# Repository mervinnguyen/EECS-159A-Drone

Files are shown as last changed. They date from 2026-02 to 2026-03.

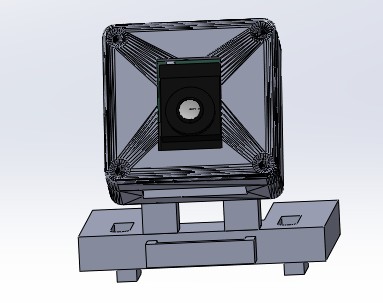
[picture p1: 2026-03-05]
3D Printed Parts/Full Camera Mount Assembly 2.jpg

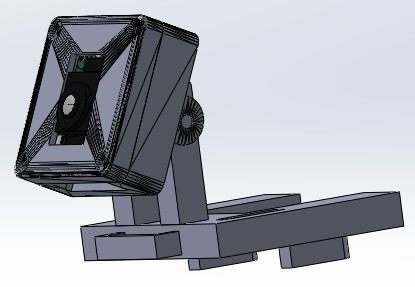
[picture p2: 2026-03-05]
3D Printed Parts/Full Camera Mount Assembly.jpg

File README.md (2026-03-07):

# PhotonFlight: Fiber-Optic Autonomous UAV

PhotonFlight is a **fiber-optic-tethered autonomous quadcopter** designed for operation in **RF-denied or GPS-degraded environments**.  
The platform replaces traditional RF telemetry with a **secure bidirectional SFP fiber link**, enabling **low-latency video streaming, real-time telemetry, and reliable command/control communication** between the UAV and ground control station.

The system integrates **ArduPilot flight control, embedded Linux module, onboard AI vision processing, and fiber-optic networking**, demonstrating a complete embedded system spanning hardware, firmware, networking, and autonomy.

---

# Abstract

PhotonFlight is a **fiber-optic tethered UAV platform** developed for search-and-rescue and infrastructure inspection applications where traditional RF communication may be unreliable or unavailable.

The system leverages **single-mode fiber optic communication via SFP transceivers** to provide:

- RF-interference immunity  
- secure high-bandwidth communication  
- low-latency telemetry and video streaming  

An onboard AI camera enables **real-time object detection and autonomous tracking**, while a companion computer processes video and coordinates communication with the flight controller.

The result is a **robust embedded UAV platform capable of operating in communication-contested environments**.

---

# System Architecture

PhotonFlight is composed of several integrated system layers that enable flight control, telemetry transmission, and onboard intelligence.

Each layer performs a specific role in the overall system.

| Layer | Responsibility |
|---|---|
| Ground Control Station | Mission planning, telemetry monitoring, system control |
| Fiber Communication Layer | Secure telemetry and high-bandwidth video transmission |
| Companion Computer | AI inference, video processing, communication bridging |
| Flight Controller | Real-time stabilization, sensor fusion, flight control |
| Motor Control | Direct actuation of propulsion system |

e
---

# Hardware Architecture

PhotonFlight is built using a combination of **commercial off-the-shelf components and custom fabricated hardware**.

## Airframe

The UAV uses an **8-inch quadcopter carbon fiber frame** providing structural mounting for propulsion, avionics, and communication hardware.

Key design considerations include:

- vibration isolation
- weight optimization
- secure component mounting

---

## Propulsion System

The propulsion system consists of:

- **Brushless DC motors (BLDC)**
- **high-efficiency propellers**
- **electronic speed controllers (ESCs)**

ESCs receive control signals from the flight controller to regulate thrust and maintain stability.

---

## Power System

The drone is powered by a **high-discharge LiPo battery** distributed through a **Power Distribution Board (PDB)**.

The power subsystem manages:

- high-current delivery
- electrical isolation
- voltage regulation for onboard electronics

Battery safety procedures and charge management protocols are implemented for safe operation.

---

# Flight Control System

The UAV uses an **ArduPilot-based flight controller** responsible for deterministic flight control.

Responsibilities include:

- attitude stabilization
- sensor fusion
- waypoint navigation
- flight mode control
- failsafe management

The controller integrates multiple onboard sensors:

- IMU (accelerometer + gyroscope)
- magnetometer
- barometer
- GPS receiver

Flight control commands are communicated via **MAVLink protocol**.

---

# Companion Computer

A **Raspberry Pi 4** acts as the onboard companion computer, providing high-level processing capabilities.

The companion computer is responsible for:

- AI inference and object detection
- video encoding and streaming
- communication routing between sensors and ground station
- system coordination

The Raspberry Pi communicates with the flight controller through **MAVLink interfaces**.

---

# Fiber-Optic Communication Pipeline

PhotonFlight replaces traditional RF telemetry with a **fiber-optic communication architecture**.

The system uses:

- **SFP transceivers**
- **single-mode fiber optic cable**
- **media converters**

This communication architecture provides several advantages:

- immunity to RF interference
- secure communication channel
- high-bandwidth data transmission
- reduced telemetry latency

Data transmitted through the fiber link includes:

- MAVLink telemetry
- AI camera video feed
- mission control commands

---

# Vision System

PhotonFlight incorporates two vision modules enabling perception capabilities.

## Infrared Camera

The infrared camera enables **thermal imaging and low-light operation**, allowing the UAV to function in environments such as:

- disaster response zones
- low visibility environments
- nighttime search-and-rescue missions

---

## AI Camera

The onboard AI camera performs **real-time object detection and tracking** using pretrained neural network models.

Capabilities include:

- autonomous target tracking
- real-time object detection
- visual feedback to ground operators

Inference can be executed onboard or streamed for external processing.

---

# Ground Control Station

A ground control station running **Mission Planner or QGroundControl** enables operators to:

- monitor real-time telemetry
- upload mission waypoints
- visualize system status
- issue control commands

Communication between the UAV and the ground station occurs over the fiber link.

---

# Safety Systems

Several redundant safety mechanisms are implemented to ensure safe operation.

These include:

- geofencing
- return-to-launch (RTL)
- emergency failsafe procedures
- pre-flight validation checklists

These systems mitigate risk during autonomous flight operations.

---

# Key Technologies

PhotonFlight integrates multiple hardware and software technologies:

**Flight Control**
- ArduPilot
- MAVLink

**Embedded Systems**
- Raspberry Pi 4
- embedded Linux

**Networking**
- fiber-optic SFP communication
- telemetry streaming

**Perception**
- onboard AI camera
- computer vision inference

---

# Documentation & Project Resources

Project documentation and development artifacts are maintained collaboratively.

Resources include:

- system architecture documentation
- hardware integration notes
- flight test logs
- telemetry data analysis
- design review presentations
- safety procedures and compliance documentation

---

# Project Focus

PhotonFlight demonstrates the integration of:

- embedded flight control systems  
- secure communication infrastructure  
- onboard AI perception  

into a UAV platform capable of operating in **RF-contested or GPS-degraded environments**.

This project highlights the application of **embedded systems engineering, networking architecture, and autonomous robotics** in real-world mission scenarios.

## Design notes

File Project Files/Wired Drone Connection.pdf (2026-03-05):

C

o

n

n

e

c

# tin

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
# Mis

# sio

n

# Pla

n

n

e

r

# Drone Info

Connection Info:
static ip_address=192.168.1.100/24 (you can find with photonflight.local; subnet mask is 255.255.255.0)
Port: 5678

Use RX4&TX4 on the flight controller side.

Pi needs to be connected to Vx and Gnd for power; reason being that Vx can supply more current than the other pins.
Currently, the Pi is connected to serial2 on the flight controller

Credentials
Username: photonflight

### Password: *rZ866Qr8!IRnr

Power:
Vx and Gnd from Servo side of the flight controller board

Camera Code Required:

rpicam-vid -t 0 \ --width 1920 --height 1080 --framerate 30 \ --codec h264 --profile high --level 4.1 --inline \ --post-process-file /usr/share/rpi-camera-assets/imx500_mobilenet_ssd.json \ -o - \ | gst-launch-1.0 fdsrc \ ! h264parse \ ! rtph264pay config-interval=1 pt=96 \ ! udpsink host=192.168.1.155 port=1110

Prof. Burke’s install script: https://github.com/mavlink-router/mavlink-router

# Mission Planner Info

Network Settings:
Laptop IP: 192.168.1.155
Subnet Mask: 255.255.255.0
Connect via TCP to port 5678

Firewall Settings:
Go to “Network & Internet” -> “Advanced Network Settings” -> “Advanced Sharing Settings” Turn on Network Discovery inside of Private Networks

Camera Code Required:
udpsrc port=1110 caps="application/x-rtp, media=video,

### encoding-name=H264, payload=96" ! rtph264depay ! h264parse ! avdec_h264 ! queue max-size-buffers=1 max-size-bytes=0 max-size-time=0 leaky=2 ! videoconvert ! video/x-raw,format=BGRA ! appsink name=outsink sync=false

# Instructions

1. Connect drone to laptop via fiber optics and ethernet
a. Raspberry pi -> ethernet -> SFP on drone
b. SFP on drone -> fiber -> SFP on laptop
c. SFP on laptop -> ethernet -> laptop

### 2. For camera make sure it is connected before the Pi gets power. Otherwise a

reboot is required.
3. First turn on drone by connecting main battery
4. Wait for flight controller to beep and for raspberry pi to turn on and run scripts
a. To check to see if the Pi is running by pinging 192.168.1.100 in the terminal
5. On Mission Planner select TCP and connect to 192.168.1.100 at port 5678
6. Mission Planner should be pulling data over the wired connection and relaying that information back to the laptop

### 7. Joystick Config:

a. Then connect the radio controller to Mission Planner via USB type C cable
b. Make sure radio controller is running in wired joystick mode
c. Go to setup -> joystick and then configure the controller

### 8. If using Fiber:

a. To start video:
i. Right Click on HUD
ii. | Hover over “Video”
iii. | Click “Set Gstreamer Source”
iv. | Paste in string from Mission Planner Info
v. Hit Enter, should get a feed onto the HUD

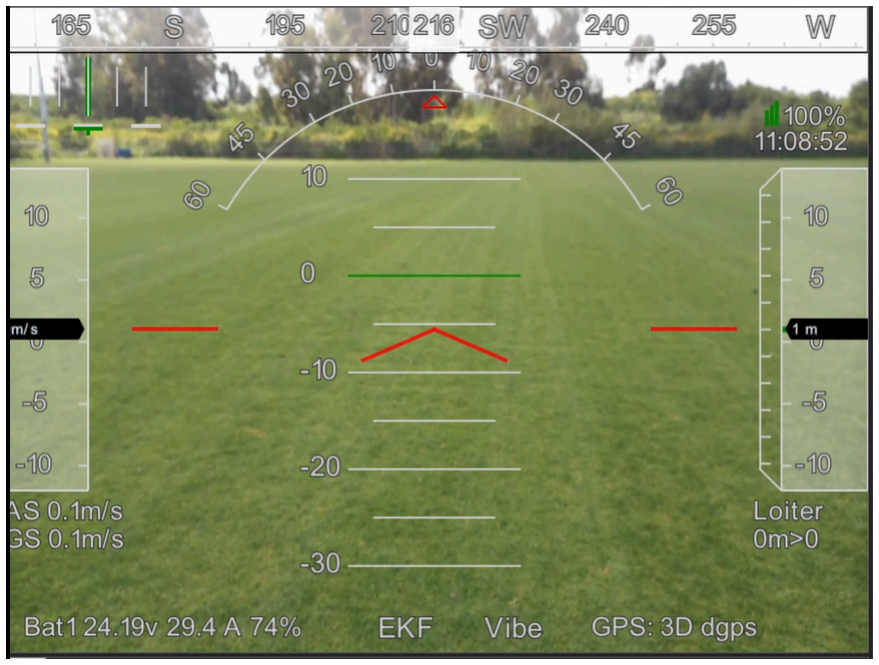
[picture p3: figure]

# Findings (1-28-26)

- We hooked up RX & TX on the flight controller side to Serial 4. Checked the parameter file and saw that baud rate & communication protocol weren’t set correctly
- Changed the baud rate to 57600 (57 in settings), and changed protocol to MavLink2 (2 in settings)
- On Pi Tx4 is plugged into GPIO 15 (Rx)
- Rx4 is plugged into GPIO 14 (Tx)
- After rebooting flight controller we are able to connect without issues

# Joystick Config

1. Setup -> Optional Hardware -> Joystick
2. https://ardupilot.org/copter/docs/common-joystick.html
3. The channels that Burke setup are going to match the RC #s listed in the setup menu
a. EX: RC1 deals with Aileron which means rolling left and right (tilt). So we hit auto detect and move the stick that deals with rolling left and right. This happens to be the one that maps to the X axis of the controller

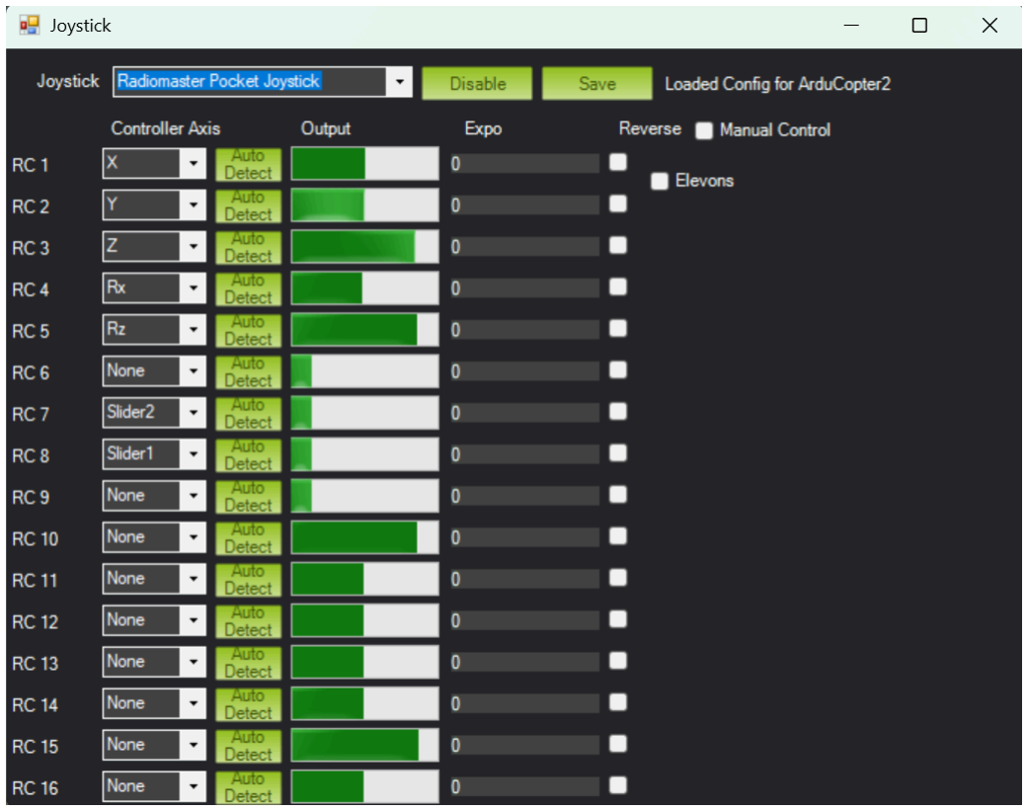
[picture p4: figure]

As of 1-28-26

# Turning On The Camera

This is assuming the connection has been setup and that you have SSH’d into the Pi.
1. First navigate to the folder with the code:
cd Projects/EECS-159A-Drone/Vision\ Tracking\ pipeline/
2. Activate the venv (Virtual Environment):
source .venv/bin/activate
3. You should now see a (.venv) in green text on the left of your terminal
4. Execute the program:
python3 Object_Tracking.py
5. Now the program will first:
a. Connect to the drone (using the same port as mission planner 5678)
b. And then upload firmware to the camera (this is when the loading bar appears)
c. A menu will print out as the loading bar appears and then will get pushed up by more text
d. TLDR it should look like this:

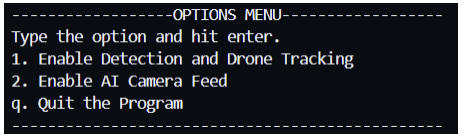
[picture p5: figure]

6. Select an option (use #2 if you do not want the drone to react to objects)
a. Press 1 or 2 and hit enter
b. Drone must be armed before it can react
c. 1 and 2 will start object detection on Mission Planner (assuming you’ve already set that up by pasting the long string into Gstreamer)
7. When you want to quit press: Ctrl + C
8. That will exit you back out to the menu; the camera glitching is normal because the program will restart the camera
9. To fully quit the menu press Ctrl + C again or press q and hit Enter

### 10. If you want to rerun the program (assuming you haven’t done anything else) just

go back to step #4

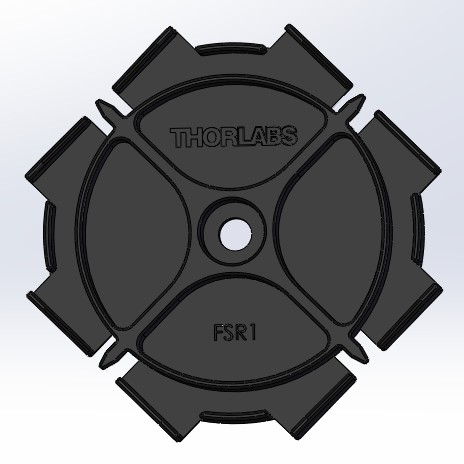
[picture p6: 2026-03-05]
3D Printed Parts/Fiber optic Cable Holder.jpg

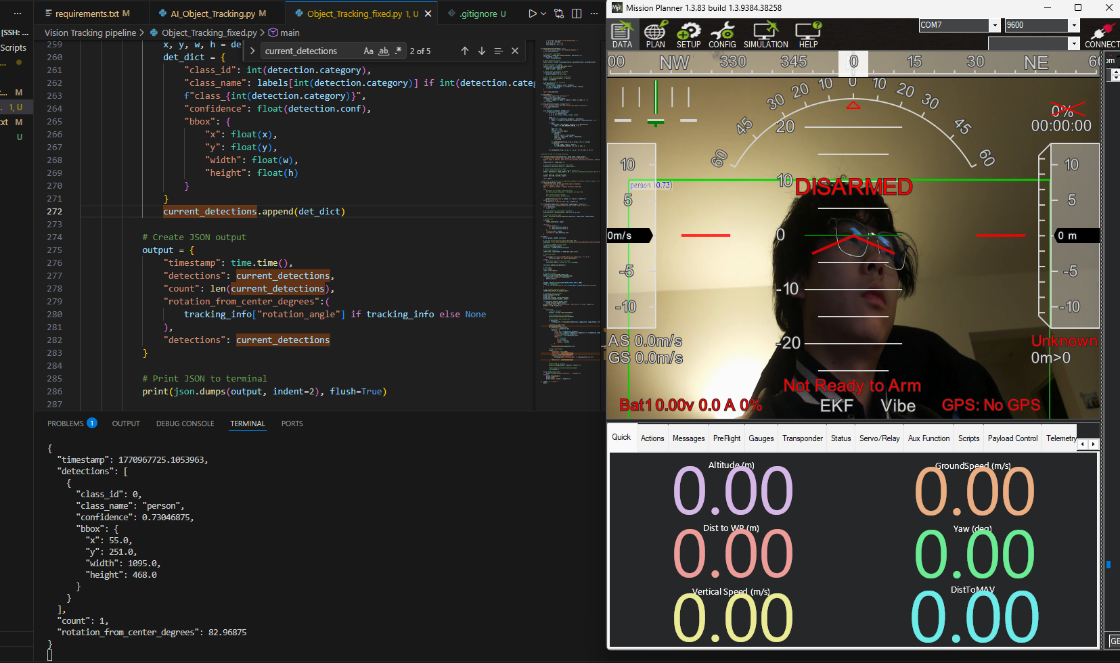
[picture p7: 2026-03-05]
Vision Tracking pipeline/assets/image.png

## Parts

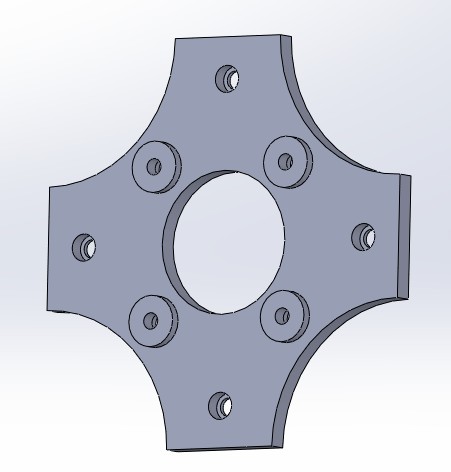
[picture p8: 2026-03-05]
3D Printed Parts/ESC Mount.jpg

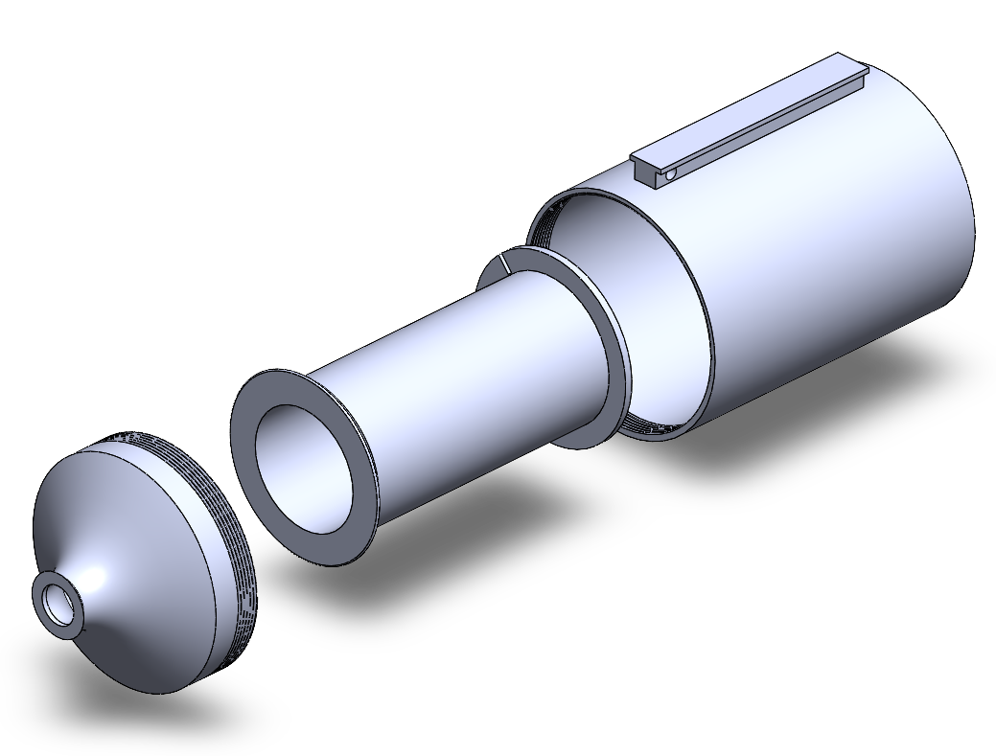
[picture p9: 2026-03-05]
3D Printed Parts/Fiber spool.png

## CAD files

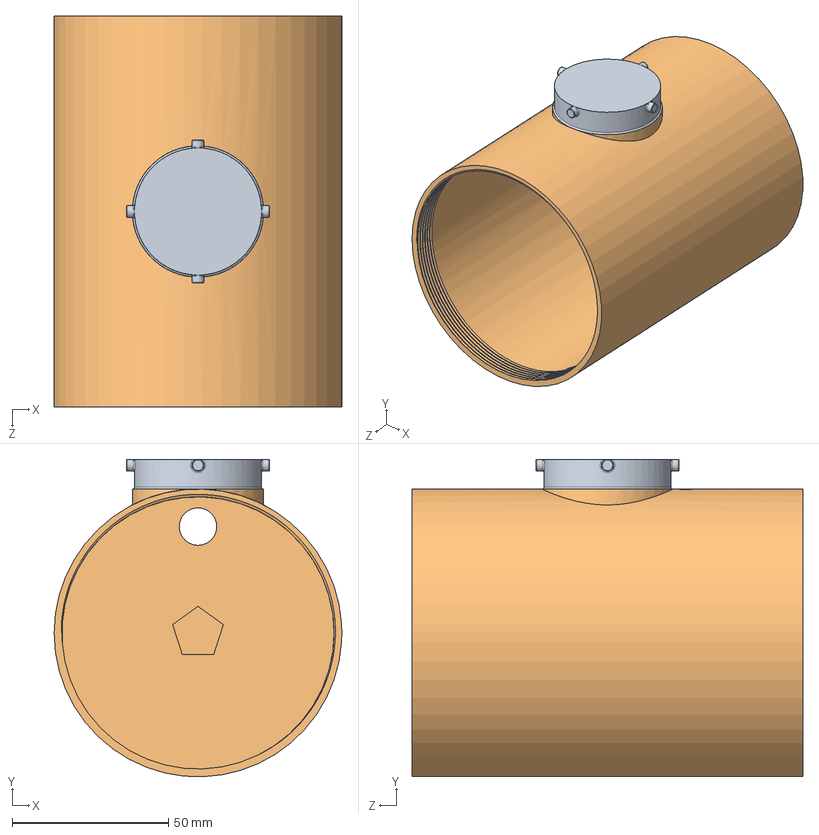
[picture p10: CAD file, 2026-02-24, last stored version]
3D Design Files/Fiber spool on drone.SLDASM
92.0 x 101.5 x 125.0 mm
New spool external housing
Twist Lock Enclosure Male

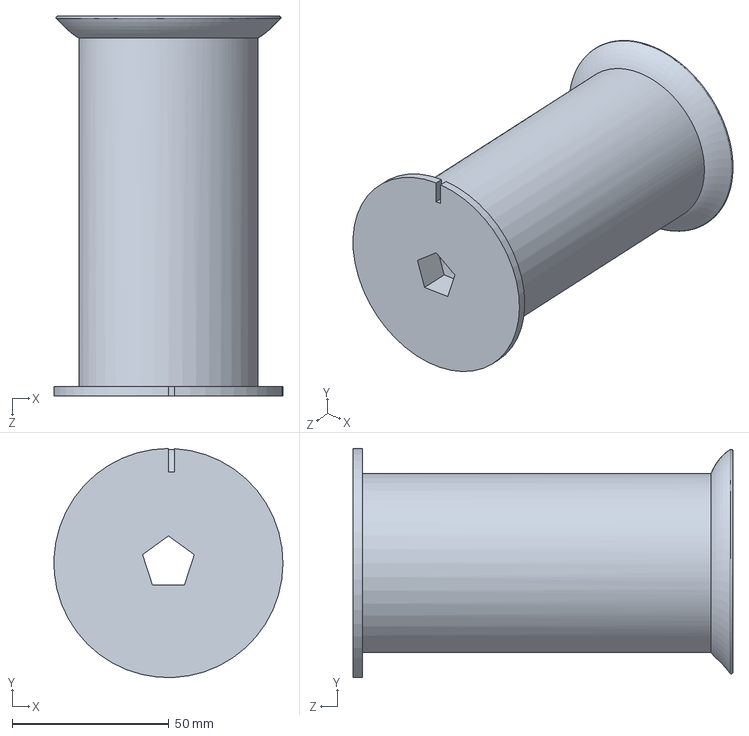
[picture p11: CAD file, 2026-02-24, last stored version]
3D Design Files/New spool internal barrel.SLDPRT
73.0 x 73.0 x 121.0 mm

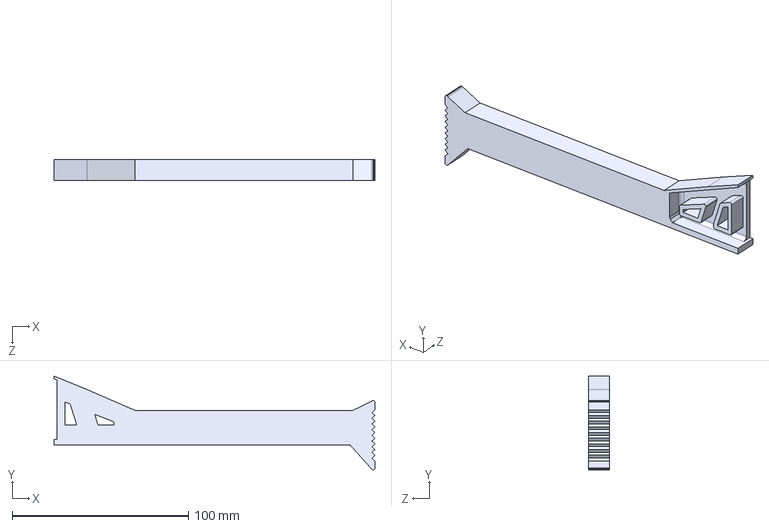
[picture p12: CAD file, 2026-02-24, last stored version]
revised_leg_2.22.26_long_af.STEP
182.3 x 53.3 x 12.0 mm

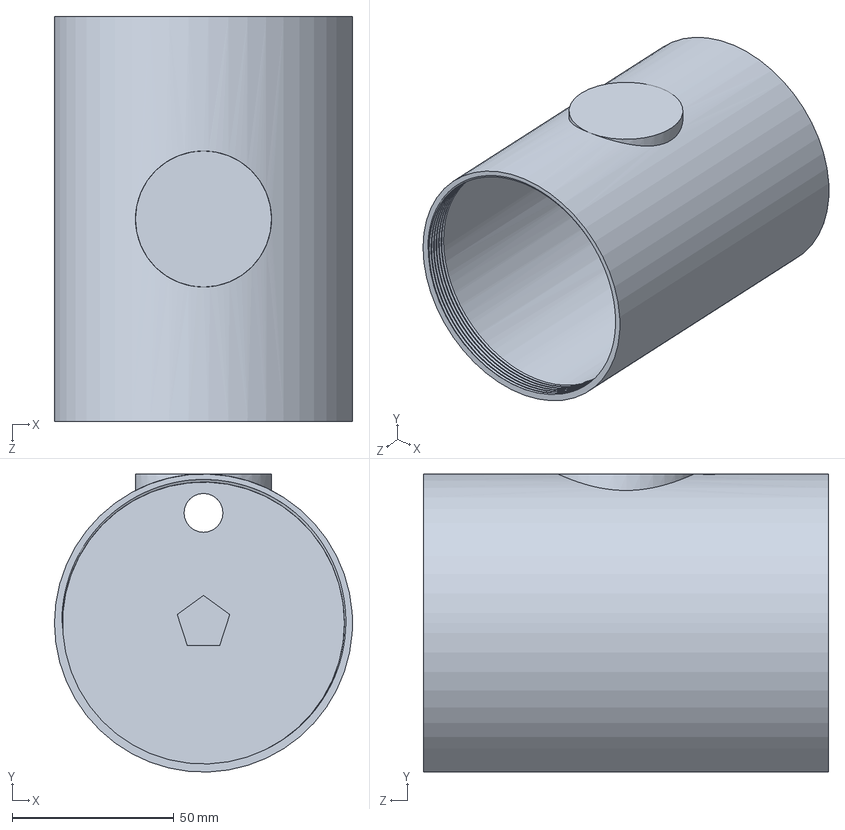
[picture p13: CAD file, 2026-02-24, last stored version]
3D Design Files/New spool external housing.SLDPRT
92.0 x 92.0 x 125.0 mm

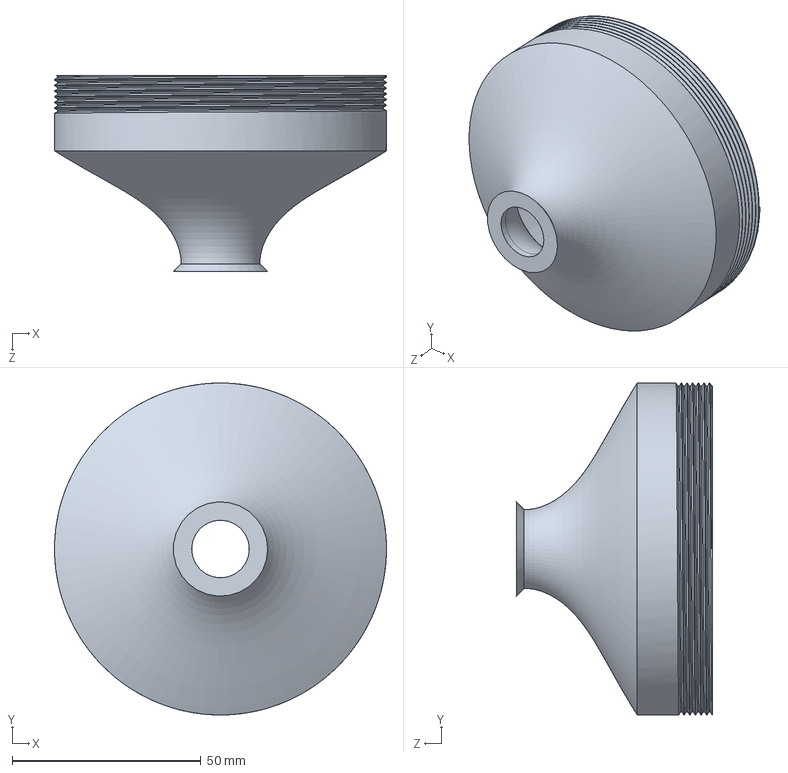
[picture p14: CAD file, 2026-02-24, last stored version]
3D Design Files/New spool external lid.SLDPRT
88.0 x 88.0 x 52.0 mm

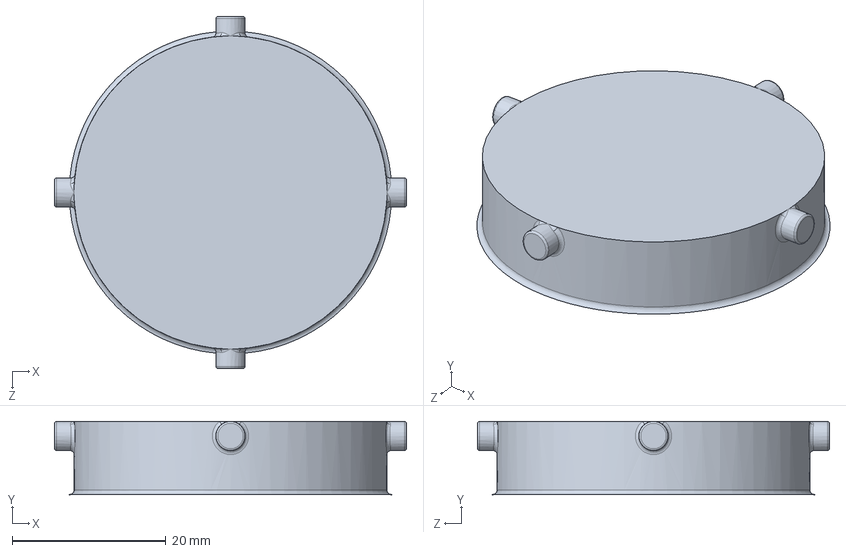
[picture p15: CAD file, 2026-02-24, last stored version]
3D Design Files/Twist Lock Enclosure Male.SLDPRT
45.7 x 9.52 x 45.7 mm

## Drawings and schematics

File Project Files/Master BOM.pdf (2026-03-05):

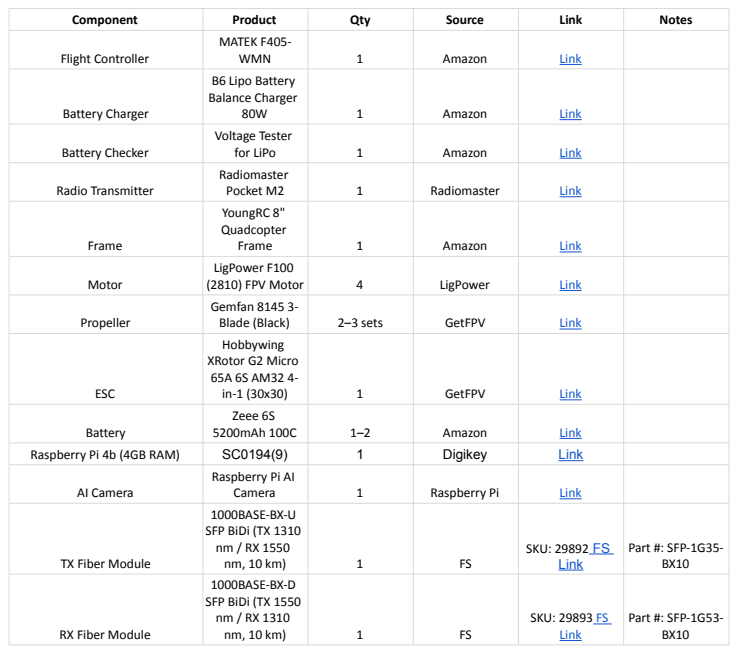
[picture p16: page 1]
Component; Product; Qty; Source; Link; Notes; Flight Controller; MATEK F405-; WMN; Amazon; Battery Charger; B6 Lipo Battery Balance Charger; Battery Checker; Voltage Tester; for LiPo; Radio Transmitter; Radiomaster; Pocket M2; Frame; YoungRC 8" Quadcopter; Motor; LigPower F100; (2810) FPV Motor; LigPower; Propeller; Gemfan 8145 3-; Blade (Black); 2–3 sets; GetFPV; ESC; Hobbywing XRotor G2 Micro 65A 6S AM32 4-; Battery; Zeee 6S; 5200mAh 100C; Raspberry Pi 4b (4GB RAM); Digikey; AI Camera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

Raspberry Pi AI
1000BASE-BX-U
SFP BiDi (TX 1310
1000BASE-BX-D
SFP BiDi (TX 1550

TX Fiber Module

RX Fiber Module

Fiber Patch Cable | Simplex LC UPC ↔ LC UPC SMF (OS2), 1.2 mm, Riser | 1 | FS | SKU: 319469 FS Link | Custom length 150 FT
Media Converter | Mini Industrial 1x RJ45 ↔ 1x 1000Base-X SFP | 1 | FS | SKU: 143413 FS Link | Part #: IMC-GA1F1T
Prototype Receiver | EP2 ExpressLRS Nano RX (2.4 GHz, 0.44 g, Ceramic Antenna) | 1 | Amazon | Link (https://www.amazon.com/gp/product/B0962M9GS6?tag=rotor-builds-20) | Prototype component
GPS | BE-880 GPS Receiver Module + Compass (38400bps, 10th Chip) | 1 | Amazon | Link (https://www.amazon.com/gp/product/B0BTM5N5GS?tag=rotor-builds-20)
DC-DC Buck Converter | Mini MP1584EN DC-DC Buck Converter Adjustable Power Supply Module | 2 | Amazon | Link (https://www.amazon.com/MP1584EN-DC-DC-Converter-Adjustable-Module/dp/B01MQGMOKI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) | Powering Media Converters
Radio Transmitter Batteries | 18650 Rechargeable Battery With 18650 Battery Charger | 1 | Amazon | Link (https://www.amazon.com/Rechargeable-AA-Batteries-Capacity-Recyclable/dp/B0DF6CPJFR?adgrpid=185194027566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)

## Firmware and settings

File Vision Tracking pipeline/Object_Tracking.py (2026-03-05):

#!/usr/bin/env python3
"""
Object Detection Script for Raspberry Pi Zero W with IMX500 AI Camera
Outputs detected objects as JSON to terminal
"""
from importlib.metadata import metadata
import json
from logging import config
import time
from unicodedata import category
import sys
import select
import cv2
import numpy as np
from picamera2 import MappedArray, Picamera2
from picamera2.encoders import H264Encoder
from picamera2.outputs import FfmpegOutput
from picamera2.devices import IMX500
from picamera2.devices.imx500 import NetworkIntrinsics
from pymavlink import mavutil

# Detection parameters
THRESHOLD = 0.55
IOU = 0.65
MAX_DETECTIONS = 10
HORIZONTAL_FOV_DEG = 60.0       #Adjust to your actual IMX500 horizontal FOV

# Streaming parameters (Mission Planner UDP)
STREAM_HOST = "192.168.1.155"
STREAM_PORT = 1110
STREAM_FPS = 60
STREAM_BITRATE_KBPS = 1500
RESOLUTION_WIDTH = 1280
RESOLUTION_HEIGHT = 720

last_detections = []
labels = []

# Overlay state
currentMode = "FEED ONLY"
prevTime = time.time()
currentFPS = 0.0

class Detection:
    def __init__(self, coords, category, conf, metadata):
        """Create a Detection object, recording the bounding box, category
and confidence."""
        self.category = category
        self.conf = conf
        self.box = imx500.convert_inference_coords(coords, metadata,
picam2)
        self.center_x = None
        self.center_y = None
        self.calculate_center()

    def calculate_center(self):
        """Calculate the center of the bounding box."""
        x, y, w, h = self.box
        self.center_x = x + w / 2
        self.center_y = y + h / 2

class DroneController:
    """ Handles MAVLink communicaiton with the drone """
    
    def __init__(self, drone_ip, drone_port):
        self.drone_ip = drone_ip
        self.drone_port = drone_port
        self.master = None
        self.connected = False

    def connect(self):
        """Connect to the drone via MAVLink"""
        connection_string = f"tcp:{self.drone_ip}:{self.drone_port}"
        print(f"Connecting to drone at {connection_string}...")
        try:
            self.master = mavutil.mavlink_connection(connection_string)
            self.master.wait_heartbeat(timeout=10)
            # This section might continue to execute even if we fail to connect to drone
            self.connected = True
            print(f"✓ Connected to drone (System ID: {self.master.target_system})")
            return True
        except Exception as e:
            print(f"ERROR: Could not connect to drone: {e}")
            return False
    
    def turn(self, angle: int):
        
        if angle < 0:
            # send counter clockwise version of command with positive angle
            self.master.mav.command_long_send(self.master.target_system, self.master.target_component, mavutil.mavlink.MAV_CMD_CONDITION_YAW, 0, abs(angle), 25, -1, 1, 0, 0, 0)
        self.master.mav.command_long_send(self.master.target_system, self.master.target_component, mavutil.mavlink.MAV_CMD_CONDITION_YAW, 0, angle, 25, 1, 1, 0, 0, 0)
        
    def close(self):
        """Close Connection to drone"""
        if self.master:
            try:
                self.master.close()
                print("Drone connection closed")
            except:
                pass


def parse_detections(metadata: dict):
    """Parse the output tensor into detected objects."""
    global last_detections

    # Get outputs from IMX500
    np_outputs = imx500.get_outputs(metadata, add_batch=True)
    if np_outputs is None:
        return last_detections

    # Parse detection results
    boxes, scores, classes = np_outputs[0][0], np_outputs[1][0], np_outputs[2][0]

    # Normalize boxes if needed
    input_w, input_h = imx500.get_input_size()
    if intrinsics.bbox_normalization:
        boxes = boxes / input_h

    # Reorder bbox coordinates if needed
    if intrinsics.bbox_order == "xy":
        boxes = boxes[:, [1, 0, 3, 2]]

    # Split boxes into individual coordinates
    boxes = np.array_split(boxes, 4, axis=1)
    boxes = zip(*boxes)

    # Filter detections by threshold
    last_detections = [
        Detection(box, category, score, metadata)
        for box, score, category in zip(boxes, scores, classes)
        if score > THRESHOLD
    ]
    
    return last_detections

def get_labels():
    """Get label names from intrinsics."""
    labels = intrinsics.labels
    if intrinsics.ignore_dash_labels:
        labels = [label for label in labels if label and label != "-"]
    return labels

def draw_detections(request, stream="main"):
    """Draw detection boxes and labels onto frames before encoding."""
    global currentMode, currentFPS

    if not last_detections:
        return

    with MappedArray(request, stream) as m:

        #Overlay Mode
        cv2.putText(
            m.array,
            f"MODE: {currentMode}",
            (20, 630),
            cv2.FONT_HERSHEY_SIMPLEX,
            0.8,
            (0, 255, 0),
            2
        )

        #Overlay fps
        cv2.putText(
            m.array,
            f"FPS: {currentFPS: .2f}",
            (20, 660),
            cv2.FONT_HERSHEY_SIMPLEX,
            0.8,
            (0, 255, 0),
            2
        )

        #bounding boxes
        for detection in last_detections:
            x, y, w, h = detection.box
            x, y, w, h = int(x), int(y), int(w), int(h)

            label = ""
            if labels and int(detection.category) < len(labels):
                label = f"{labels[int(detection.category)]} ({detection.conf:.2f})"

            if label:
                (text_width, text_height), baseline = cv2.getTextSize(
                    label, cv2.FONT_HERSHEY_SIMPLEX, 0.5, 1
                )
                text_x = x + 5
                text_y = y + 15
                overlay = m.array.copy()
                cv2.rectangle(
                    overlay,
                    (text_x, text_y - text_height),
                    (text_x + text_width, text_y + baseline),
                    (255, 255, 255),
                    cv2.FILLED
                )
                cv2.addWeighted(overlay, 0.30, m.array, 0.70, 0, m.array)
                cv2.putText(
                    m.array, label, (text_x, text_y),
                    cv2.FONT_HERSHEY_SIMPLEX, 0.5, (0, 0, 255), 1
                )

            cv2.rectangle(m.array, (x, y), (x + w, y + h), (0, 255, 0, 0), 2)


# Section of code for rotating the drone

def calculate_rotation_angle(detection, image_width):
    """Calculate the rotation angle needed to face the detection center.
    Returns angle in degrees, where 0 is facing forward, positive is clockwise, negative is counterclockwise.
    """
    image_center_x = image_width / 2

    # Calculate horizontal deviation from center
    deviation = detection.center_x - image_center_x

    print("Deviation is: ", deviation)

    # Convert pixel deviation to angle
    degreesPerPixel = HORIZONTAL_FOV_DEG / image_width
    angle = deviation * degreesPerPixel  # Assuming a 60 degree horizontal FOV for the camera

    return angle

def track_object(detections, image_width):
    """Track the most confident detection and rotate drone to face it."""
    if not detections:
        return None

    # Get the detection with highest confidence
    best_detection = max(detections, key=lambda d: d.conf)

    # Calculate rotation angle
    angle = calculate_rotation_angle(best_detection, image_width)
    
    return {
        "target_center": {
            "x": best_detection.center_x,
            "y": best_detection.center_y
        },
        "rotation_angle": angle,
        "confidence": best_detection.conf
    }

def enable_tracking(flight_controller, picam2, image_width, turn: bool):
    global prevTime, currentFPS

    now = time.time()
    currentFPS = 1.0 / (now - prevTime)
    prevTime = now

    # Capture metadata
    metadata = picam2.capture_metadata()

    # Parse detections from metadata
    detections = parse_detections(metadata)

    # Track object and rotate drone
    tracking_info = {"rotation_angle": 0}
    if detections:
        tracking_info = track_object(detections, image_width) or tracking_info
    
    # Convert to JSON format
    current_detections = []
    for detection in detections:
        x, y, w, h = detection.box
        det_dict = {
            "class_id": int(detection.category),
            "class_name": labels[int(detection.category)] if int(detection.category) < len(labels) else
            f"class_{int(detection.category)}",
            "confidence": float(detection.conf),
            "bbox": {
                "x": float(x),
                "y": float(y),
                "width": float(w),
                "height": float(h)
            }
        }
        current_detections.append(det_dict)
    
    # Create JSON output
    output = {
        "timestamp": time.time(),
        "detections": current_detections,
        "count": len(current_detections),
        "rotation_from_center_degrees": tracking_info["rotation_angle"],
        "detections": current_detections
    }

    if turn:
        flight_controller.turn(tracking_info["rotation_angle"])

    # Print JSON to terminal
    print(json.dumps(output, indent=2), flush=True)

    # Small delay to avoid overwhelming output
    #time.sleep(0.5)

def print_menu():
    print("------------------OPTIONS MENU------------------")
    print("Type the option and hit enter.")
    print("1. Enable Detection and Drone Tracking")
    print("2. Enable AI Camera Feed")
    print("q. Quit the Program")
    print("------------------------------------------------")

def main():
    global picam2, imx500, intrinsics, labels, currentMode
    
    # Load the object detection model (MobileNet SSD)
    model_path ="/usr/share/imx500-models/imx500_network_ssd_mobilenetv2_fpnlite_320x320_pp.rpk"

    # Initialize IMX500 with the model
    imx500 = IMX500(model_path)
    intrinsics = imx500.network_intrinsics

    # Get image dimensions
    image_width = RESOLUTION_WIDTH
    print("Image Width is: ", image_width)

    # Load COCO labels.
    try:
        with open("/usr/share/imx500-models/coco_labels.txt", "r") as f:
            intrinsics.labels = f.read().splitlines()
    except:
        # Fallback labels if file not found
        intrinsics.labels = [str(i) for i in range(80)]
    
    intrinsics.update_with_defaults()

    # Get labels
    labels = get_labels()

    # Connect to Mission Planner:
    flight_controller = DroneController('127.0.0.1', '5678')
    if(flight_controller.connect() is False):
        print("Program cannot connect to drone. Program exiting...")
        return 1


    # Initialize camera
    picam2 = Picamera2(imx500.camera_num)
    config = picam2.create_video_configuration(
        main={'size': (RESOLUTION_WIDTH, RESOLUTION_HEIGHT)},
        controls={"FrameRate": STREAM_FPS},
        buffer_count=12
    )

    encoder = H264Encoder(bitrate=STREAM_BITRATE_KBPS * 1000)
    output = FfmpegOutput(
        f"-f rtp -payload_type 96 rtp://{STREAM_HOST}:{STREAM_PORT}?pkt_size=1200"
    )

    # Show firmware loading progress
    imx500.show_network_fw_progress_bar()

    # Configure and start camera
    picam2.configure(config)
    picam2.start()
    picam2.pre_callback = draw_detections
    picam2.start_encoder(encoder, output)

    if intrinsics.preserve_aspect_ratio:
        imx500.set_auto_aspect_ratio()
    print("IMX500 Object Detection Program Running - Press Ctrl+C to stop", flush=True)
    print("-" * 60, flush=True)

    try:
        while True:
            print_menu()
            try:
                option = input("Type and enter your selection: ").strip().lower()
            except KeyboardInterrupt:
                print("\nStopping object detection...", flush=True)
                break

            match option:
                case '1':
                    currentMode = "FEED + ACTIVE YAW"
                    print("Tracking + drone turning enabled. Press Ctrl+C to return to menu.")
                    try:
                        while True:
                            enable_tracking(flight_controller, picam2, image_width, turn=True)
                    except KeyboardInterrupt:
                        # The reason I put this in is because when we exit out of tracking mode, the camera stops sending the feed unless I restart it
                        picam2.stop_encoder()
                        picam2.stop()
                        picam2.configure(config)
                        picam2.start()
                        picam2.pre_callback = draw_detections
                        picam2.start_encoder(encoder, output)
                        print("\nReturning to options menu...", flush=True)

                case '2':
                    print("AI camera feed enabled. Press Ctrl+C to return to menu.")
                    try:
                        while True:
                            enable_tracking(flight_controller, picam2, image_width, turn=False)
                    except KeyboardInterrupt:
                        picam2.stop_encoder()
                        picam2.stop()
                        picam2.configure(config)
                        picam2.start()
                        picam2.pre_callback = draw_detections
                        picam2.start_encoder(encoder, output)
                        print("\nReturning to options menu...", flush=True)

                case 'q':
                    print("Quitting program...", flush=True)
                    break

                case _:
                    print("Invalid option. Please enter 1, 2, or q.", flush=True)

    except KeyboardInterrupt:
        print("\nStopping object detection...", flush=True)
    finally:
        flight_controller.close()
        picam2.stop_encoder()
        picam2.stop()
        print("Camera stopped.", flush=True)

if __name__ == "__main__":
    main()

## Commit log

2025-10-02 Expand README with new camera and companion computer details
    Added sections for IR Camera, AI Camera, and Raspberry Pi 4 in the README.
2025-10-02 Fix formatting of AI Camera and Raspberry Pi sections
2026-02-13 Working live camera feed with detections. Got angles to work again and setup project structure for ease of duplication.
2026-02-13 Fix calculate_rotation_angleve direction is clockwise.
    [Object_Tracking.py]
2026-02-17 Checking to see if there is a detection before printing rotation angle
2026-02-17 Fixed angle issue. Now properly detects offset from camera center.
    [Object_Tracking.py]
2026-02-21 Calculate current fps for tracking stage
2026-02-24 Add files via upload
    Drone Leg 3D file
    [revised_leg_2.22.26_long_af.STEP]
2026-02-24 Create CAD Models
